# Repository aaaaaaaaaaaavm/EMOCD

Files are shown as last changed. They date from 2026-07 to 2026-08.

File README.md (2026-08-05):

# VOLLEY: an electromagnetic orbital CubeSat deployer

> **Numerical audit correction, 2026-08-03.** I corrected the winding-thickness quadrature
> and propagated the rated point to **11.03 N per kA/m, 16.388 m/s, 10.53 g, 20.99% net
> efficiency, and 65.552 N s per shot**. I also corrected A13's internal-momentum physics,
> replaced A6's fixed-shape covariance claim with a valid current-geometry slab bound,
> extended A12's stress plane, removed a 0.344 kg brake-fin double count, and corrected the
> fin thermal mass. Superseded values remain visible in their validation records and
> change log.

<p align="center">
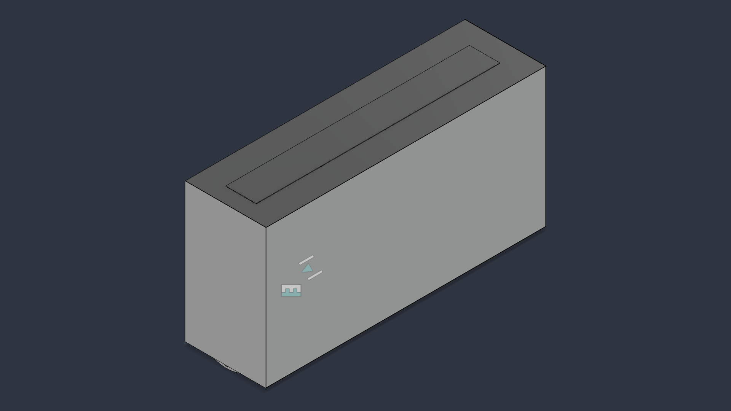
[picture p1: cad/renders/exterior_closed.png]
VOLLEY deployer, closed, mounted on its ESPA interface
  
</p>






A magazine-fed electromagnetic deployer that ejects unmodified CubeSats from a host
stage at programmable velocity, aimed at the unserved regime between spring deployers
(~2 m/s) and propulsive orbital transfer vehicles (hundreds of m/s).

**Status: design study, TRL 2-3.** Phase I CAD is complete across 9 Fusion 360 documents in three
generations, with Gen3 STEP exports committed. A provisional Gen4 open assembly exists in Fusion
but has no rated operating point or repository export yet ([status](docs/GEN4_STATUS.md)). **Nine of eleven planned validations
have run** — **two of them failed**, one found a published number 37 % high, and one returned
three rows that could not be evaluated at all. **Nothing has been built and nothing has been measured
at any scale.**
**Read `docs/PROVENANCE.md` before citing anything here.**

**[📄 One-page summary](SUMMARY.md)** · **[🧊 Frozen baseline](docs/BASELINE.md)** · **[Gen4 status](docs/GEN4_STATUS.md)** · **[🗺 Roadmap](docs/ROADMAP.md)** · **[⚠ Open problems](OPEN_PROBLEMS.md)** · **[✓ Validation](docs/VALIDATION_REPORT.md)** · **[🏗 Manufacturing](docs/MANUFACTURING.md)** · **[📐 ADRs](docs/adr/)** · **[📚 Literature](docs/LITERATURE.md)** · **[🎯 Research position](docs/RESEARCH_POSITION.md)** · **[⛔ Velocity ceiling](docs/VELOCITY_CEILING.md)** · **[☠ Kill criteria](docs/KILL_CRITERIA.md)** · **[🏁 Phase I closure](docs/PHASE_I_CLOSURE.md)** · **[📦 Payload classes](docs/PAYLOAD_CLASSES.md)** · **[📈 Market](docs/MARKET.md)**

<!-- PROGRAMME-HEADER-START -->
| Repository | Role | You are here |
|---|---|---|
| **[VOLLEY](https://github.com/aaaaaaaaaaaavm/VOLLEY)** | Flagship, authoritative engineering record, portfolio | |
| [VOLLEY-paper](https://github.com/aaaaaaaaaaaavm/VOLLEY-paper) | IEEE companion, manuscript and reproducibility package *(generated)* | |
| [VOLLEY-thesis](https://github.com/aaaaaaaaaaaavm/VOLLEY-thesis) | Thesis companion, university submission *(generated)* | |
| [VOLLEY-lab](https://github.com/aaaaaaaaaaaavm/VOLLEY-lab) | Phase II, research, redesign, deliberately unstable | |
<!-- PROGRAMME-HEADER-END -->

Four repositories, one programme, see **[`docs/PROGRAMME.md`](docs/PROGRAMME.md)**.

## The idea

CubeSats flown as rideshare secondaries inherit the primary customer's orbit. The
spring that ejects them adds 1-2 m/s, enough to drift clear, not enough to change an
orbit. A satellite with no propulsion of its own is stuck there for life.

VOLLEY replaces the spring with an ironless double-sided Halbach linear synchronous
motor driving a reusable magnetic sled along a 1.5 m track. Twelve 3U CubeSats feed
from two transverse cassettes and are fired one at a time. The satellite is never
modified, the magnets ride the sled, not the payload.

<table>
<tr>
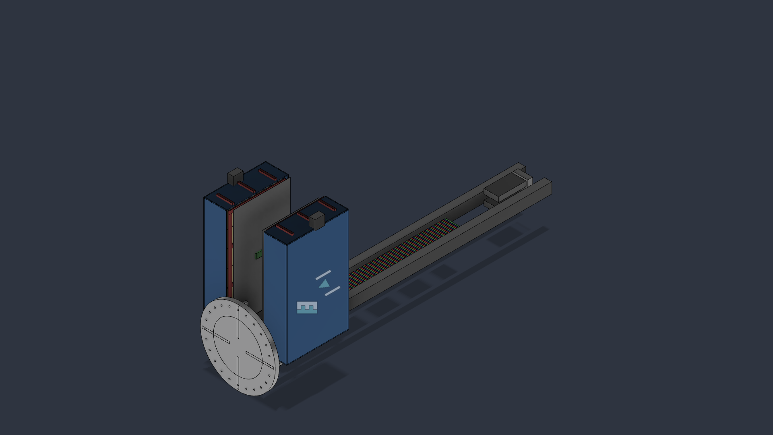
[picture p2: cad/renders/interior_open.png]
Interior, enclosure open
<td width="50%"><br><sub><b>Interior.</b> Track, stator belts, sled, and both cassettes with the enclosure open.</sub></td>
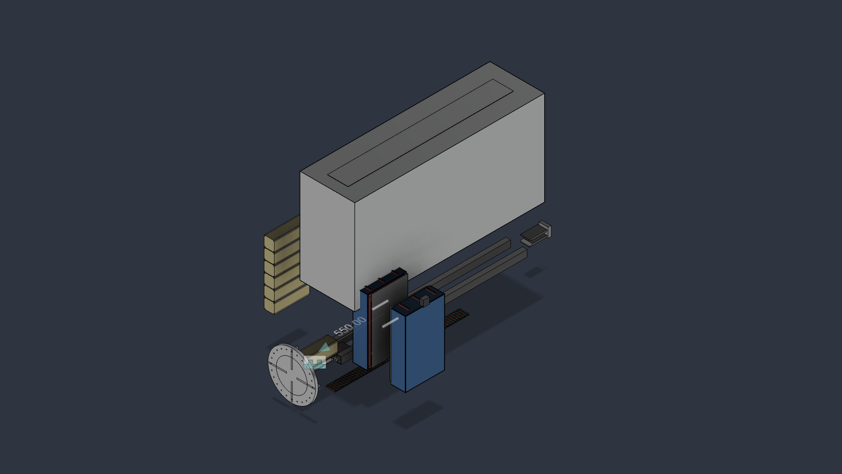
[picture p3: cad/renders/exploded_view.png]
Exploded view of the nine documents
<td width="50%"><br><sub><b>Exploded.</b> The nine documents: track, stator, sled, cassettes, brake, ESPA interface, enclosure, payload.</sub></td>
</tr>
<tr>
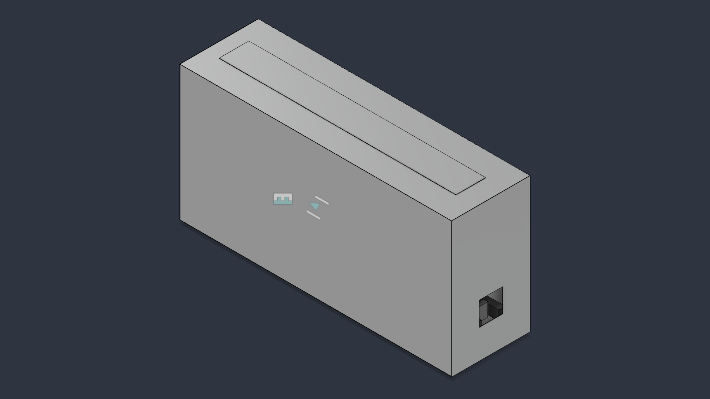
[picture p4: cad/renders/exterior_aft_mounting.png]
Aft ESPA mounting interface
<td width="50%"><br><sub><b>Aft mounting.</b> Ø460 mm ring flange, Ø400 mm bolt circle, 24 holes, four gussets.</sub></td>
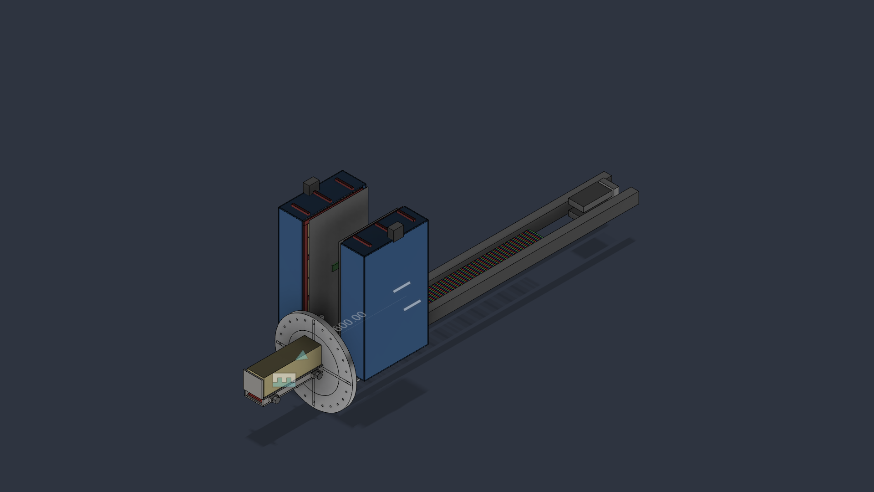
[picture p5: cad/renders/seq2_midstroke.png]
Sled at mid-stroke
<td width="50%"><br><sub><b>Mid-stroke.</b> Sled under thrust, payload still cradled, 158.6 ms from breech to release.</sub></td>
</tr>
</table>

**Spin it in the browser:** [`cad/stl/EMOCD_Assembly_Gen3.stl`](cad/stl/EMOCD_Assembly_Gen3.stl)
and [`cad/stl/EMOCD_Sled_Gen3.stl`](cad/stl/EMOCD_Sled_Gen3.stl), GitHub renders STL
natively, so click either and drag. They are derived meshes; `cad/step/gen3/` is the master
geometry ([why](cad/stl/README.md)).

## How a shot works

```mermaid
flowchart LR
    A["Cassette feed<br/>12 x 3U, two cassettes"] --> B["Retention gate<br/>preload into structure"]
    B --> C["Accelerate<br/>1.3 m, 10.5 g, 158.6 ms"]
    C --> D["Coast &amp; trim<br/>0.2 m"]
    D --> E["Release at 1500 mm<br/>16.39 m/s"]
    E --> F["Eddy brake<br/>1530-1740 mm"]
    F --> G["Sled recovered<br/>reusable, next shot"]
    E -.->|"payload departs"| H["Own orbit<br/>x1.62 lifetime"]
```

The satellite is never modified: the magnets ride the sled, not the payload. The sled leaves
release carrying 1268 J; 240 mm of stator past that point takes **291 J of it back into the
bank**, and the eddy brake absorbs the remaining 935 J. Efficiency is quoted
electrical-to-payload, net of that credit.

## Headline results (all model outputs, not measurements)

> ### The pulse-power chain does not close on purchasable cells
>
> **Found 2026-07-30, and stated here rather than left in the defect log.** The supercapacitor
> bank is modelled at 12 mÎ©. Commercial cells of this capacitance give **116 to 185 mÎ©**, and
> the shot stops completing above **65 mÎ©**: a source behind resistance R cannot deliver more
> than V²/4R, and this one is asked for 30 kW.
>
> **Exit velocity, stroke time and dispersion are unaffected** and the mechanical design is not
> implicated. What is affected is that the rated point assumes a bank nobody can buy. Fixing it
> is a sizing decision, costed at four parallel strings in `docs/PHASE_II.md` PII-7, and it is
> **not** silently applied here. See **P26**.

| Quantity | Value | Source |
|---|---|---|
| Thrust constant | 11.03 N per kA/m, ±0.99 % ripple, **independently computed by FEM to 0.03 %** | `analysis/motor_model.py`, A1 |
| Exit velocity, 3U | **16.39 m/s at 10.5 g** | `analysis/motor_model.py` |
| Electrical to payload efficiency | 21.0 % (2.56 kJ net of regeneration, 537 J delivered) | `analysis/motor_model.py` |
| Closed-loop dispersion | 0.027 m/s (3σ) at a 16.2 m/s setpoint to ±0.10 km apogee | `analysis/motor_model.py` |
| Orbital lifetime multiplier | x1.62 at mean activity, **not invariant, see P16** | `analysis/astro.py` |
| Constellation seeding | 30° in 1.4-6.9 days vs 25 days by differential drag | `analysis/astro.py` |
| Dry / loaded mass | 76.5 kg / 124.5 kg | `analysis/mass_properties.py` |
| Recoil per shot | 65.6 N·s | `analysis/astro.py` |
| Track first mode | 109 Hz fixed-fixed (target >70) | `analysis/sizing.py` |
| Energy closure | 100.0 % accounted | `analysis/sizing.py` |

> ### These numbers moved on 2026-07-29, downward
>
> The headline used to read **20.37 m/s at 16.3 g**, computed against a 4.86 kg parametric
> sled. Exact solid volumes from the Gen3 CAD give **9.445 kg**: the plates are drawn
> solid, with no pocketing (P15).
>
> That was not resolved by picking a number.
> [`validation/A4_sled_structural.md`](validation/A4_sled_structural.md) fixed the
> consequence of each outcome **before** the structural analysis ran:
>
> | Measured mass | Declared consequence |
> |---|---|
> | ≤ 5.35 kg | parametric model stands, 20.37 m/s holds |
> | 5.35-6.80 kg | neither estimate right |
> | **≥ 6.80 kg** | **the headline changes and the paper changes materially** |
>
> A4 has since run, the drawn plate passes all three structural bands, so nothing forces a
> lighter chassis, and the CAD result landed in the third branch. The scripts moved
> first, then the paper. Writing the rule down in advance is what made that a procedure
> rather than a preference.
>
> **What this costs and does not cost.** Exit velocity is down 19 % and efficiency from
> 32 % to 20 %, and to 19 % after the ESR correction of 2026-07-30 (P24); regeneration has
> then took it to 21.2 % (A11); the corrected quadrature now gives 21.0 %. The lifetime multiplier is down only 10 %, x1.80 to x1.62, because lifetime
> is a weak function of Î”v, the mission case survives better than the machine spec does.
> 9.445 kg is the **as-drawn, unpocketed** geometry, and A4 reports a 17x stress margin, so
> a rib-stiffened chassis would recover mass. Nobody has designed one
> ([`docs/ROADMAP.md`](docs/ROADMAP.md)).
>
> Ways to recover the velocity, pocketing, sheet current, stroke length, a two-layer
> stator, and a momentum-transfer release that buys it all back for 1.6 % of the shot
> energy, are costed in
> [`docs/DESIGN_OPTIONS_exit_velocity.md`](docs/DESIGN_OPTIONS_exit_velocity.md).

Three results have independent cross-checks: the Halbach field model (analytic vs
magpylib, agreeing to three digits, and again vs a meshed magnetostatic FEM, a PDE
solve rather than another superposition, agreeing on the corrected thrust constant to 0.03 %),
and orbital decay (orbit-averaged vs Cowell RK4, 99.4 %). Everything else is
single-sourced.

## Reproducing

```bash
pip install -r requirements.txt
cd analysis
python3 verify_field.py && python3 mass_properties.py && python3 motor_model.py && python3 sizing.py && python3 astro.py
```

Results land in `analysis/results/*.json`.

The analysis layer needs nothing but `requirements.txt`. The **validation** layer needs
external solvers, gmsh and scikit-fem for the magnetostatic FEM, GetDP, CalculiX,
ngspice, and a LaTeX install for the manuscript. `tools/env-setup.sh` installs all of
them on a Debian/Ubuntu machine and verifies each one before exiting.

<table>
<tr>
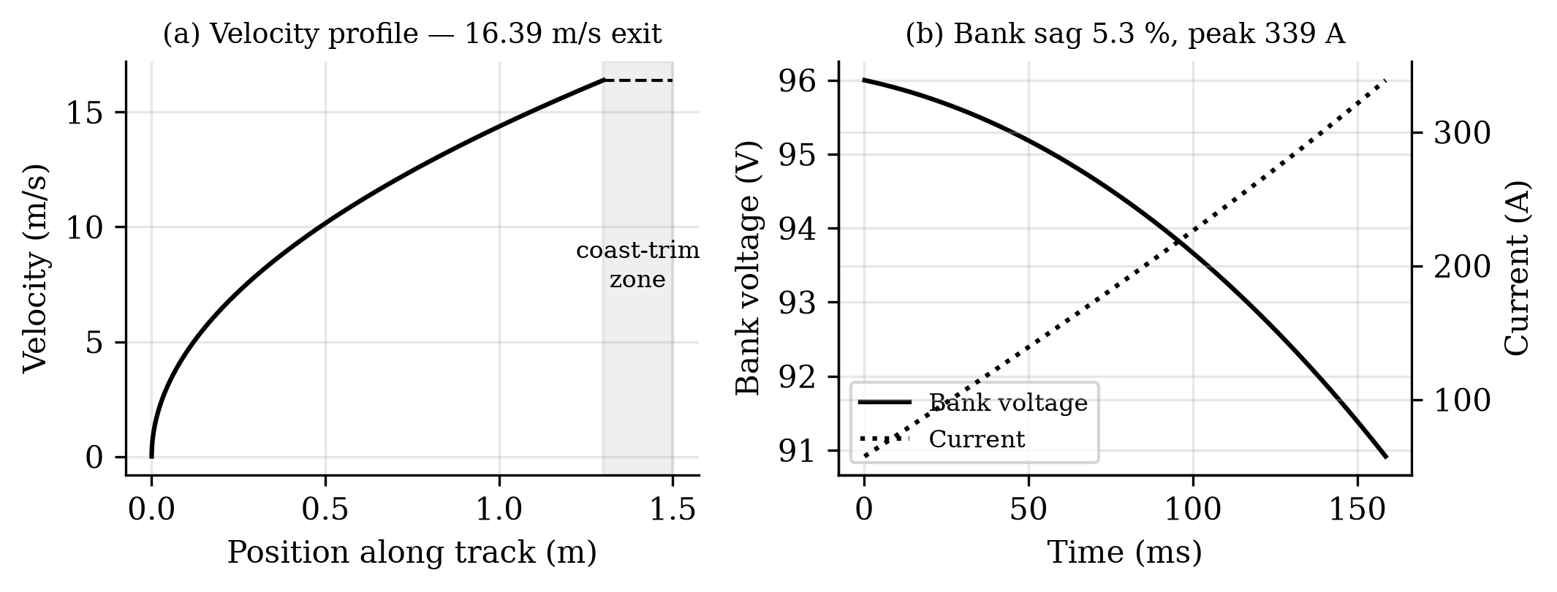
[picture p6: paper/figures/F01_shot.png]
Shot simulation: force, velocity, current
<td width="50%"><br><sub><b>The shot.</b> Force, velocity and current through the 158.6 ms stroke (<code>motor_model.py</code>).</sub></td>
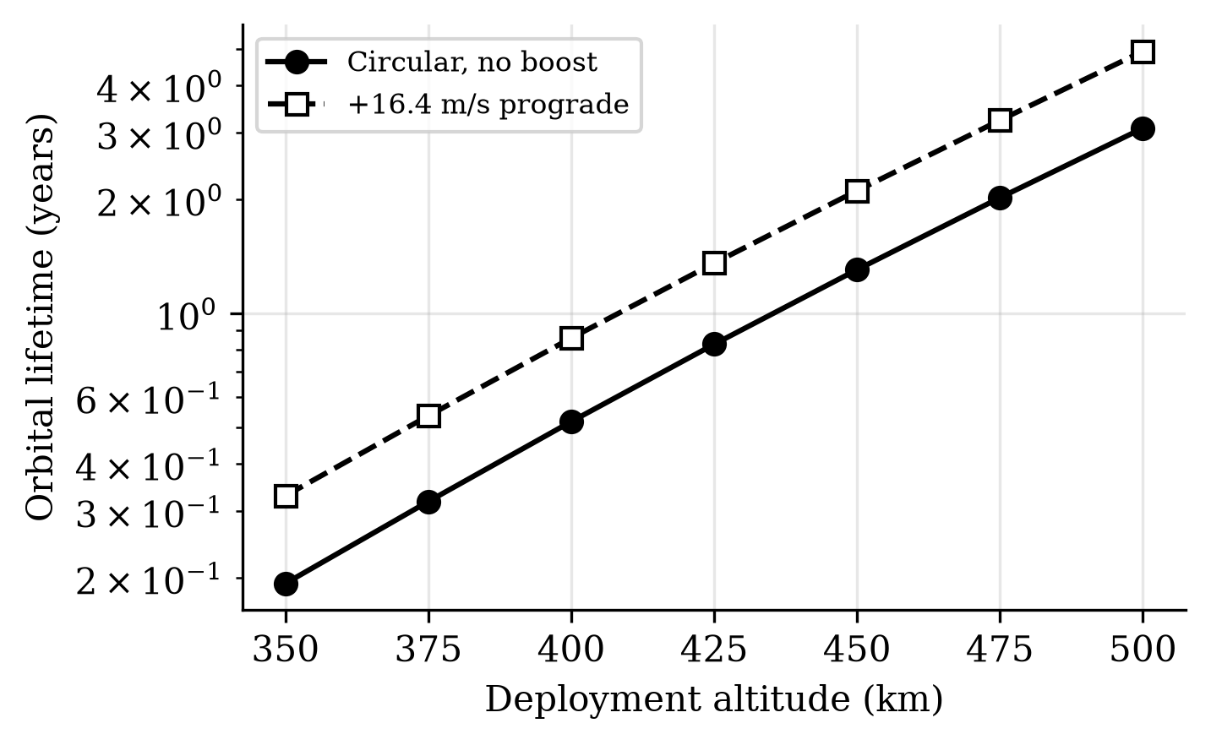
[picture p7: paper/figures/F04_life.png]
Orbital lifetime with and without the boost
<td width="50%"><br><sub><b>Lifetime.</b> Boosted vs unboosted decay, the x1.62 multiplier at mean activity is the current model result, not the absolute years (<code>astro.py</code>).</sub></td>
</tr>
</table>

## Validation

**[`docs/VALIDATION_REPORT.md`](docs/VALIDATION_REPORT.md)**: every claim, independently checked
where possible. Four analyses were actually run; three could not be.

- **Reproducibility holds exactly**: 173 values re-computed from clean, 173 identical.
- **GMAT falsified the invariance claim.** It reproduced the old x1.80 multiplier at mean
  and high solar activity but gave 2.074 at low, an 18.5 % spread against a ≤5 % band.
  `astro.py` varies solar activity by scaling density uniformly, and ballistic coefficient
  enters the same multiplicative slot, so *both* halves of that claim were tested by a sweep
  that could not have detected a problem (**P16**).
- **CalculiX** cleared the chassis on all three structural bands, which is what settled the
  sled mass at the CAD-derived **9.445 kg** and moved the headline to 16.54 m/s (**P15**), before the quadrature correction moved it to 16.39 m/s.
- **ngspice** reproduced the then-current shot model to 0.03 % and then, re-run at the then-current operating
  point, found a loss the analytic model had no term for at all: the bank's own series
  resistance, 86 J a shot (**P24**). Corrected, the two methods agree on peak current to
  0.01 %. It also found the quoted bank sag is state-of-charge, not the terminal voltage the
  drive sees.
- **A1 and A10--A13 have been propagated to the corrected point. A5 and the ngspice A8 run predate it** (**P19**) and needs
  re-running. A4 survives, its load being magnetostatic and velocity-independent.
- **A1 has run (2026-07-29).** A meshed 2-D magnetostatic FEM gives K<sub>t</sub> = 11.026 N
  per kA/m against the model's 11.03, **ratio 0.9997**, ripple 0.97 % against 0.99 %. The
  number every headline descends from is no longer checked only analytic-against-analytic.
  Two of seven bands missed, both with identified causes and neither a model error (P20, P21).
- **Not run:** A6, A7, A9.

## Charts

Full set in **[`docs/RESULTS.md`](docs/RESULTS.md)**: all drawn by GitHub from text, no image files.
Two that carry the argument:

```mermaid
pie showData
    title Energy per shot (J) - sizing.py energy_closure
    "Sled KE to the eddy brake" : 935
    "Payload KE, the useful output" : 537
    "Copper loss, shot + regen" : 850
    "Converter loss" : 111
    "Bank ESR loss" : 91
    "Auxiliary" : 35
```

537 J reaches the payload out of a **net 2560 J**: 2851 J leaves the bank and 291 J returns.
That is the 21.0 %. Efficiency fell with the heavier sled twice over, because more of the same
mechanical work goes into a mass that is then braked away and the longer 159 ms pulse accrues
more copper loss at unchanged current density. Regeneration is the first thing that has moved
it the other way.

**This page said "no regeneration credit" until 2026-07-31**, on the strength of a 2025
decision that argued the motor cannot *arrest* the sled. It cannot, and the brake stays. It was
never shown that no energy could be recovered, and
[`validation/A11_regen_braking.md`](validation/A11_regen_braking.md) found 23.0 % of the sled's
energy available inside the existing envelope at the existing current rating.

The 86 J ESR slice was not here until 2026-07-30. No script modelled the bank's series
resistance, so the loss existed in the hardware and nowhere in the accounting. A circuit
simulation found it (P24).

```mermaid
xychart-beta
    title "Minimum approach vs ejection velocity - not a robust quantity"
    x-axis "Ejection velocity (m/s)" [20.00, 20.37, 20.50, 20.65, 21.00]
    y-axis "Minimum approach (km)" 0 --> 70
    line [37.5, 4.6, 56.1, 45.3, 63.4]
```

A ±2.5 % velocity change moves the conjunction minimum from 4.6 km to 63.4 km. That is why
the paper's safety claim rests on the realignment period, now 9.9 days at the current
operating point, instead of a single distance (P1). The sweep above was computed at the
superseded 20.37 m/s point and is kept as the evidence for P1; the fragility it demonstrates
is a property of the beat geometry, not of any one velocity.

## Validation status

Each analysis has its acceptance band declared **before** the run, in
[`validation/`](validation/). A5 has now been run under GMAT; the rest have not, a cross-check whose target is chosen after seeing the
answer proves nothing.

| Analysis | Tool | Closes | Status |
|---|---|---|---|
| A1 airgap field | FEMM | E1 (2-D half), E2 | specified |
| **A4 sled chassis** | CalculiX ccx 2.21 | **P5, P8** | **run**: as-drawn plate passes; mass unchanged |
| A5 lifetime & seeding | GMAT R2022a | E6 | **run**: see [`docs/RESULTS.md`](docs/RESULTS.md) |
| A6 conjunction Pc | NASA CARA | P1 | specified |
| A7 separation & tip-off | Project Chrono | E7 | specified |
| A8 pulse-power chain | ngspice 42 | E17 | **run**: bands met, 2 findings |

## Host integration, worked against real vehicles

The interface asks four things of any host: mass and control authority, a 150-300 W recharge
feed, a serial command link, and an authorized firing window. Two Indian candidates are
worked as examples in the paper because both exist today.

**ISRO's POEM** is the flown precedent, a spent PS4 stage operated as a three-axis-stabilized
hosted platform with solar power, NavIC navigation and helium attitude thrusters, retired by
controlled reentry. It supplies everything the attached variant borrows, and its zero-debris
closeout is the regulatory template.

**Skyroot Aerospace's Vikram-1** carries a restartable liquid Orbit Adjustment Module, one
Raman-2 engine, four Raman Mini thrusters, eight cold-gas thrusters, stage-tested through more
than a thousand pulses, whose stated multi-orbit deployment role is functionally the PS4's.
Against the vehicle's published 350 kg LEO capacity, a loaded VOLLEY is **34 %**, falling to
**22 %** and **13 %** on the announced 550 kg and 900 kg family members. Early flights are
therefore dedicated demonstrations and later ones ordinary manifest items.

One integration quantity cannot be closed from public data: the OAM's mass and control
authority are undisclosed, which is why the recoil budget is parametric. Obtaining stage mass,
thruster impulse budget and coast duration is the single data exchange that converts this
analysis from parametric to specific, for any candidate vehicle, Indian or otherwise.

Recoil is the satellite's momentum only, **65.6 N·s** per shot, nulled by a few grams of cold
gas. Comparison against fielded deployers and transfer vehicles, including Dhruva Space's
flown DSOD, is in [`docs/LANDSCAPE.md`](docs/LANDSCAPE.md).

## Repository layout

- `analysis/`, current scripts; these reproduce the numbers above
- `analysis/femm/`, FEMM magnetostatics package: `emocd_cross_section.dxf` + `FEMM_RUN_SHEET.md` (analysis A1, not yet run)
- `cad/`, Fusion 360 CAD: `parameters.json` (geometry source of truth, 9 documents),
  `step/gen1|gen2|gen3/` exports (**Gen3 current**), `stl/` (browser-viewable meshes),
  `renders/`, `CHANGELOG_CAD.md` (generation history and per-file defect list)
- `legacy/`, superseded scripts, kept for history, **do not cite**
- `paper/`, IEEE conference paper (LaTeX source, figures, PDF)
- `validation/`, independent cross-check plan (FEMM, CalculiX, Orekit, CARA, Chrono),
  each with an acceptance band declared before the run; nothing run yet
- `docs/`, computation notes, FEMM run sheet, related work and comparator sources
- `docs/PROJECT_NOTES.md`, working context: ground rules, layout, locked decisions
- `docs/LANDSCAPE.md`, how this compares with deployers that actually fly
- `docs/DESIGN_OPTIONS_exit_velocity.md`, options for the P15 velocity shortfall, costed
- `docs/INVENTORY.md`, complete indexed catalogue of every calculation, decision and artifact
- `docs/DECISION_LOG.md`, why each design change happened, including two self-corrections
- `docs/PROVENANCE.md`, what came from where, and what was never verified
- `OPEN_PROBLEMS.md`, known errors in the paper, and unsolved engineering
- `docs/PROGRAMME.md`, the four repositories and how they relate
- `docs/BASELINE.md`, the frozen Phase I baseline (generated) and its change-control rule
- `docs/GEN4_STATUS.md`, provisional open-assembly geometry and the export/performance gate
- `docs/HISTORY.md`, project timeline since 2021, and how the git history was reconstructed
- `docs/programme/`, the governing dossier, adopted verbatim, plus its amendment record
- `docs/adr/`, nineteen architecture decision records
- `docs/PHASE_II.md`, deferred work and the gate it must clear to return
- `docs/MANUFACTURING.md`, tolerance stack, assembly hazard, make-vs-buy
- `docs/CROSS_INDUSTRY.md`, which open items are actually solved elsewhere
- `docs/QUALIFICATION_PLAN.md`, environmental and qualification campaign, specified not run
- `docs/BENCHTOP_TESTS.md`, four cheap sub-scale experiments, bands declared in advance
- `analysis/cost.py`, parametric BOM; every price assumed, structure is the deliverable

## Known issues

The published paper previously contained four numbers its own scripts did not reproduce
(conjunction minimum, peak current, far-field stray values, brake fin temperature rise),
all found by reconstructing the analysis from scratch. **All four were corrected in
`paper/paper.tex` on 2026-07-23 to match the scripts**, and the conjunction claim was
additionally reframed because that minimum is not a robust quantity. Note that
`paper/archive/EMOCD_submission_uncorrected.pdf` still carries the uncorrected values,
whether that build is the one that was submitted is open (`OPEN_PROBLEMS.md` P11). Full record with
cause, before/after, and references is in `CHANGELOG.md`; the original defects remain
documented in `OPEN_PROBLEMS.md` P1, P4 for the audit trail.

**Two issues are live rather than historical, and both sit in the paper:**

- **P16, the invariance claim in the abstract is falsified.** GMAT reproduces the x1.80
  lifetime multiplier at mean and high solar activity but gives x2.074 at low, an 18.5 %
  spread against a ≤5 % band. The reason is that `astro.py` varies solar activity by scaling
  density uniformly, which preserves a ratio *by construction*, and the ballistic-coefficient
  half of the same sentence is the identical construction, since `scale` and `1/BC` occupy the
  same slot in the drag term. Neither half of that claim was ever tested by a method capable
  of falsifying it. **`paper/paper.tex` still asserts it in five places, including the
  abstract**, because there is no TeX engine here and editing the source without rebuilding
  the PDF would split the two.
- **P11, which build was actually submitted is unresolved.** Until that is answered, it is
  not known whether the version of record carries P1, P4 *and* the falsified abstract claim.

Newest entries: **P26** (the supercapacitor bank cannot source the shot on purchasable
cells), **P28** (the regeneration stator and the eddy fin do not both fit the arrest section)
and **P29** (the paper says the winding is segmented; the model charges copper for all
1.3 m). Most recently closed: **P17**, the inter-array attraction feeding the A4 FEA, 37 %
high — resolved by A12, which also found that P17's *explanation* of its own finding was
backwards.

## Author

**Adityavardhan Mishra**: Department of Mechanical Engineering, Symbiosis Institute of
Technology, Symbiosis International (Deemed University), Pune. Project begun April 2021.

📧 [adityavardhanmishr@gmail.com](mailto:adityavardhanmishr@gmail.com)

Questions, corrections and reproduction attempts are all welcome, particularly reproduction
attempts. If a number in this repository does not reproduce for you, that is a defect and I
want to know. See [`docs/CONTRIBUTING.md`](docs/CONTRIBUTING.md).

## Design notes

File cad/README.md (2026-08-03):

# CAD

Fusion 360 CAD for VOLLEY, across nine documents (Track, Stator, Sled, Payload_3U,
Magazine_Cassette, Brake, Interface_ESPA, Enclosure, Assembly), in **three generations**.

Full generation history, per-file body counts, and the defect list are in
[`CHANGELOG_CAD.md`](CHANGELOG_CAD.md).

## Generations

| Folder | What it is | Status |
|---|---|---|
| `step/gen3/` | Parameter-reconciled revision, plus `EMOCD_Gen3.step`, a monolithic single-file model (395 solids) holding all nine sub-systems. The renders in `renders/` came from it | **CURRENT.** Open problems P5, P12 are indexed against it |
| `step/gen2/` | First structured revision. Mechanism-level detail arrives: single-layer stator, sled Halbach arrays and rollers, magazine escapement and D6 pins, brake ring spring | SUPERSEDED, carries a 360 mm sled chassis where the spec says 488 mm |
| `step/gen1/` | The original CAD, 2021-2025. Structural envelope rather than mechanism model; the geometry `parameters.json` was reverse-engineered from. Includes the pre-split single-file `EMOCD_Deployer_Assembly_Gen1.step` and a second sled revision, `Sled_Gen1b` | SUPERSEDED, heritage only |

Use Gen3 unless you specifically need a heritage comparison.

## What is authoritative here

- **`parameters.json` is the geometry source of truth.** Every dimension lives here, not
  in Fusion (Fusion user parameters are document-scoped and drift silently across the nine
  documents). Change a value here, then regenerate the affected document from script. If
  the CAD and `parameters.json` disagree, `parameters.json` wins and the CAD is wrong.
- CAD is authoritative for **geometry, fit, and interference only.**
- `analysis/*.py` remains authoritative for **mass and performance.** Fusion-computed
  masses are proxies (solid-copper stator, solid-aluminium CubeSats, steel standing in for
  NdFeB) and are deliberately excluded from `parameters.json`. **Never quote a
  Fusion-computed mass.**

## Status (2026-07-28)

First-pass CAD, **no structural or magnetic FEA behind any of it.** Several values are
flagged `PROVISIONAL_PENDING_FEA` in `parameters.json`. Open: the sled chassis mass (P5),
the resulting exit velocity (P8), the ESPA envelope overrun (P9), the incomplete mass
rollup (P10), and the CAD-side geometry defects P14, see `../OPEN_PROBLEMS.md`.

**What changed on 2026-07-28.** The previously committed `step/*.step` set was a
mixed-generation snapshot matching no single generation, and two of its files were stubs:
the stator export contained **one solid** rather than 162 conductors, and the ESPA
interface contained **one solid** rather than a flange ring, hub plate, and four gussets.
It was replaced wholesale by the three audited generations. See `CHANGELOG.md` (CAD2 block)
and `OPEN_PROBLEMS.md` P13.

## Before using any file

1. **Gen3 unless you need heritage.** Gen1 and Gen2 carry known dimensional and mechanism
   defects, listed per file in `CHANGELOG_CAD.md`.
2. **Cross-check every dimension against `parameters.json`** before quoting it.
3. **No Fusion masses.** Mass authority is `analysis/mass_properties.py`, and even that is
   incomplete (P10).
4. **The sled mass conflict is resolved (2026-07-29).** The scripts now carry the CAD-derived 9.445 kg and the headline is 16.39 m/s. Historical note follows: 20.37 m/s assumed a 4.86 kg sled; the Gen3
   geometry implies ~7.50 kg and a provisional 17.88 m/s. Quote neither without the
   conflict (P5, P8). `validation/A4_sled_structural.md` is the analysis that settles it.
5. **The ESPA envelope claim is not supported.** 1839 mm installed against a ~1270 mm class
   limit, ~44 % over (P9), and the paper still asserts compatibility (P12).
6. **The stator layer count is an open design decision.** Gen1 built two layers, Gen2 and
   Gen3 one, and `parameters.json` flags it open. The electromagnetic consequence, roughly
   x2 force for the same current against x2 copper mass and winding complexity, has never
   been computed (P14).

## Contents

- `parameters.json`, the 9-group geometry parameter set, source of truth
- `CHANGELOG_CAD.md`, generation history, per-file inventories, defect IDs (G1-D*, G2-D*,
  G3-D*), and the cross-generation comparison
- `step/gen1/`, `step/gen2/`, `step/gen3/`, STEP exports (`.f3d` is not diffable, so STEP
  is what gets committed)
- `renders/`, exterior, interior, exploded, and firing-sequence PNGs, from the Gen3
  monolithic model

The 2-D magnetic cross-section and its FEMM run sheet live in `../analysis/femm/`.

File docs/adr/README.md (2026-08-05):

# Architecture Decision Records

Required by the Engineering Programme Dossier and the TRB prompt. One file per decision, in a
fixed shape, so a decision can be audited without reading a narrative.

**[`../DECISION_LOG.md`](../DECISION_LOG.md) is not superseded.** It is the readable history
and remains the better document for understanding *how the project got here*. These records are
the structured view: what was decided, what else was considered, what it costs, and how it gets
validated. Where an ADR has a Context section, that prose usually came from the decision log.

## Template

```
# ADR-NNN, title

Status · Date · Phase
## Context, the forces at play, including what was not known
## Decision, what was decided, stated flatly
## Alternatives, what else was considered, and why it lost
## Consequences, what this costs, including the bad parts
## Validation, how we would find out this was wrong
```

**The Consequences and Validation sections are the ones that matter.** A record listing only
benefits is advocacy, not a decision record, and one with no validation path violates dossier
§7, every feature needs a path toward validation.

## Index

| ADR | Decision | Status | Phase |
|---|---|---|---|
| [001](001-electromagnetic-deployment.md) | Electromagnetic deployment instead of a spring | Accepted | Concept |
| [002](002-host-is-a-spent-upper-stage.md) | Host is a spent upper stage, not a free-flyer | Accepted | Concept |
| [003](003-linear-synchronous-motor.md) | Linear synchronous motor, not a coilgun | Accepted | **Load-bearing** |
| [004](004-ironless-stator.md) | Ironless stator | Accepted | I |
| [005](005-eddy-brake-not-regeneration.md) | Eddy-current brake; sled energy is dissipated | Accepted | I |
| [006](006-magnets-ride-the-sled.md) | Magnets ride the sled; the CubeSat is unmodified | Accepted | **Load-bearing** |
| [007](007-dual-transverse-cassettes.md) | Dual transverse cassettes | Accepted | I |
| [008](008-retention-gate.md) | Retention gate separates preload from release | Accepted | I |
| [009](009-coast-and-trim.md) | Coast-and-trim release zone | Accepted | I |
| [010](010-host-agnostic-interface.md) | Host-agnostic four-item interface | Accepted | I |
| [011](011-publish-publicly.md) | Publish publicly, defects included | Accepted | I |
| [012](012-adopt-measured-sled-mass.md) | Adopt the measured 9.445 kg sled | Accepted | I |
| [013](013-drop-invariance-claim.md) | Drop the lifetime-ratio invariance claim | Accepted | I |
| [014](014-fleet-setpoint-below-ceiling.md) | Fleet setpoint at 98.2 % of the open-loop ceiling | Accepted | I |
| [015](015-derive-not-paste.md) | Derive coupled values; never paste them | Accepted | I |
| [016](016-reconstructed-history.md) | Reconstruct git history with labelled dates | Accepted | I |
| [017](017-four-repositories.md) | Four repositories, two of them generated | Accepted | I |
| [018](018-programme-name.md) | VOLLEY is the programme name; EMOCD_ remains the part prefix | Accepted | Programme |
| [019](019-gen4-open-assembly-before-export.md) | Keep Gen4 open assembly separate from the Phase I baseline | Accepted | Gen4 transition |
| [020](020-inter-shot-cadence.md) | The inter-shot cadence is 1200 s, closing P31 | Accepted | Load-bearing |

Every decision in `DECISION_LOG.md` appears above. ADRs 012-018 record decisions that were
never written down anywhere before.

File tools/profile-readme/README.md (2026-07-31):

## Adityavardhan Mishra

**Mechanical engineer. Powertrain, ECUs, CubeSat deployment. Asking spacecraft inconvenient questions.**

BTech Mechanical Engineering, Symbiosis Institute of Technology, Pune · 2023-2027

In 2021 I got stuck on a dumb question: why do we still deploy CubeSats with springs. I never
really got unstuck. That question is now **VOLLEY**: an electromagnetic deployer that ejects
unmodified 3U CubeSats at a programmable velocity, around seven times what a spring gives you, from a
spent rideshare upper stage. I've presented it at DRDO ARDE and the India Science Festival.

Before that there was rocketry, where our payload took **2nd globally** at the SDL Payload
Challenge, IREC 2025 in Texas. Alongside it there are engines, I run Poona Motor Club, tune Royal
Enfield, KTM and Honda platforms, and when Powertronic's map files turned out to be an obfuscated
binary I reverse-engineered the format and built a dual-map editor so I could stop guessing. This
year I'm on powertrain for our Formula Student team.

Aerospace, telecom software, engines. I have a hunch they all come from the same place. Haven't
proven it yet.

---

### The thing I'd actually like you to look at

**[VOLLEY](https://github.com/aaaaaaaaaaaavm/VOLLEY)**, a magazine-fed ironless double-sided
Halbach linear synchronous motor that ejects unmodified CubeSats at 16.5 m/s, 10.7 g, on a net
2.58 kJ a shot. TRL 2-3, nothing built, nothing measured.

**Open it for the defect record, not the numbers.** Thirty-one numbered defects, published as I
find them, including the ones that damage the claims. An independent propagator falsified a claim
in my paper's own abstract; that's P16, logged rather than quietly dropped. The supercapacitor bank
turns out not to be buyable at the resistance the design assumes, which is P26 and is on the front
page. A force I'd been feeding into my own structural FEA was 37 % too high, and when I chased it
down, the *explanation* I'd written for it was backwards too.

**Acceptance bands go in the repository before each analysis runs**, so a miss can't be
rationalised afterwards. Three rows of one analysis came back not-pass and not-fail but **void** —
the quantity they tested didn't exist — and they're recorded that way, because a band you can
reinterpret isn't a band.

That habit is the actual portfolio: **[skills, with the file that proves each one](https://github.com/aaaaaaaaaaaavm/VOLLEY/blob/main/docs/SKILLS.md)**

| | |
|---|---|
| 🛰 **[VOLLEY](https://github.com/aaaaaaaaaaaavm/VOLLEY)** | The engineering record. Start at `SUMMARY.md` |
| 📄 **[VOLLEY-paper](https://github.com/aaaaaaaaaaaavm/VOLLEY-paper)** | IEEE manuscript + reproducibility package. Reproduces from a clean clone |
| 🎓 **[VOLLEY-thesis](https://github.com/aaaaaaaaaaaavm/VOLLEY-thesis)** | Final-year submission |
| 🧪 **[VOLLEY-lab](https://github.com/aaaaaaaaaaaavm/VOLLEY-lab)** | Where I'm allowed to break things. Nothing here is citable |

---

### What I actually do

**Simulation**: scikit-fem, gmsh, GetDP, CalculiX, ngspice, GMAT, magpylib. I wrote a 2-D
magnetostatic FEM from the weak form to check my own thrust constant; it agreed to 0.07 %, which
was the first time that number rested on a PDE solve instead of superposition.

**CAD/CAE**: Fusion 360, SolidWorks, AutoCAD, ANSYS. Three CAD generations of the deployer, all
in the repo as STEP.

**Engines**: combustion airflow, head porting, camshaft profiling, ECU calibration. 46 to ~60 bhp
on an RE Super Meteor 650, dyno-validated across the band.

**Code**: Python for the numerics, MATLAB, C. Applied AI at work: I own AI systems architecture
and product design for a telecom CRM platform, which is not what I was hired to do.

<sub>Hindi and English native · Marathi, Maithili · Russian, French elementary. Friends call me AVM,
pronounced how it's spelled, *Aevium*. Recognised by the ISRO Chairman for aerospace STEM
outreach; member, Space Generation Advisory Council.</sub>

📫 [adityavardhanmishr@gmail.com](mailto:adityavardhanmishr@gmail.com) ·
[LinkedIn](https://www.linkedin.com/in/adityavardhanmishra/) · Pune, India

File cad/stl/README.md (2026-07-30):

# STL meshes: derived, not authoritative

GitHub renders `.stl` in an interactive viewer and does **not** render STEP, so these two
meshes exist purely so the geometry can be spun in a browser. Click either file above.

**These are derived artifacts.** `../step/gen3/*.step` is the master geometry and
`../parameters.json` is the source of truth for every dimension. A mesh is a faceted
approximation, never measure anything off it.

| File | Source | Mesh size | Triangles | Bounding box |
|---|---|---|---|---|
| `EMOCD_Assembly_Gen3.stl` | `../step/gen3/EMOCD_Assembly_Gen3.step` | 40 mm max | 50,692 | 1995x 530x 940 mm |
| `EMOCD_Sled_Gen3.stl` | `../step/gen3/EMOCD_Sled_Gen3.step` | 8 mm max | 23,332 | 616x 172x 140 mm |

Regenerate with:

```python
import gmsh
gmsh.initialize()
gmsh.option.setNumber('Mesh.CharacteristicLengthMax', 40)   # 8 for the sled
gmsh.option.setNumber('Mesh.CharacteristicLengthMin', 10)   # 2 for the sled
gmsh.option.setNumber('Mesh.Binary', 1)
gmsh.merge('../step/gen3/EMOCD_Assembly_Gen3.step')
gmsh.model.mesh.generate(2)
gmsh.write('EMOCD_Assembly_Gen3.stl')
gmsh.finalize()
```

`pip install gmsh` (its OCC reader handles STEP). On a headless Linux box it also needs
`libglu1-mesa libxft2 libxinerama1 libxcursor1 libfontconfig1`.

Each mesh was checked against its STEP source by bounding box on generation. The sled
matches exactly at 616x 172x 140 mm. The assembly measures 1995 mm in X against a
point-cloud bound of 1998 mm on the STEP, the 3 mm is spline control points lying outside
the surface they define, which is expected and harmless.

**One thing the assembly mesh exposes:** its X range is −188 to 1810 mm, where
`parameters.json` records the installed envelope as −32 to 1807 mm. Something sits 156 mm
further aft than the recorded envelope. See `../../OPEN_PROBLEMS.md` P14.

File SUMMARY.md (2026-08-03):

# VOLLEY: one page

**Adityavardhan Mishra** · Dept. of Mechanical Engineering, Symbiosis Institute of
Technology, Symbiosis International (Deemed University), Pune
· [adityavardhanmishr@gmail.com](mailto:adityavardhanmishr@gmail.com)
· [full repository](https://github.com/aaaaaaaaaaaavm/VOLLEY)

---

## The idea

Rideshare CubeSats inherit the orbit of whoever paid for the launch. Spring deployers release
them at **1-2 m/s**, which is far too little to change that orbit; orbital transfer vehicles
can change it, but they cost hundreds of m/s of propulsion and a spacecraft to carry it.
Between those sits an unserved regime.

**VOLLEY is a magazine-fed linear synchronous motor** that mounts on a rideshare upper stage
and ejects **unmodified** 3U CubeSats, no armature, no plating, no electrical interface on
the customer satellite, at a **velocity programmable per satellite**. Twelve satellites feed
from two transverse cassettes onto a reusable permanent-magnet sled running a 1.5 m ironless
double-sided Halbach track, arrested by a contactless eddy brake and powered from a
supercapacitor bank.

One shot buys a propulsion-less satellite **1.62x its orbital lifetime**, or seeds 30° of
constellation phase spacing in **1.4-6.9 days** against roughly 25 for differential drag.

## The numbers, with their caveats attached

| | | |
|---|---|---|
| Exit velocity, 3U | **16.4 m/s at 10.5 g** | **6.6x the fastest published spring** (NRCSD-E specifies 0.5-2.5 m/s; the widely quoted "8x" is against 2 m/s and is the softer comparison). The ceiling is the payload's g-limit, not the machine: 25.3 m/s at the 25 g cap, see [`VELOCITY_CEILING.md`](docs/VELOCITY_CEILING.md). From a sled mass computed from CAD solid volumes (9.445 kg), not estimated, the earlier 4.86 kg parametric estimate gave 20.4 m/s |
| Velocity dispersion | **0.027 m/s (3σ)** | Closed-loop, at a 16.2 m/s setpoint. Rests on *assumed* sensor noise (E7), the differentiator, and the least validated part |
| Thrust constant | **11.03 N per kA/m** | Winding-resolved, and **independently computed by a meshed magnetostatic FEM to 0.03 %**, a PDE solve, not another superposition |
| Energy per shot | **2.85 kJ gross, 2.56 kJ net**, 21.0 % electrical-to-payload | Under one watt-hour. 291 J of the sled's 1268 J comes back through 240 mm of regen stator ([A11](validation/A11_regen_braking.md), adopted 2026-07-31); the brake still takes 935 J |
| System mass | **76.5 kg dry**, 124.5 kg loaded | **6.38 kg of deployer per 3U satellite**, the same class as canisterized dispensers at ~2 kg/U |
| Recurring hardware | ~₹1.35 M per unit, ₹112 k per satellite | **Every price assumed, no quotations.** Useful part: avionics + energy storage are ~42 % of cost and the magnet set only ~5 %, which holds even at 2x price errors |
| Envelope | 1839 mm closed | **Exceeds the ESPA-Grande class by ~44 %.** Open packaging problem (P9) |

> **Open as of 2026-07-30:** the supercapacitor bank is modelled at an ESR no commercial cell
> of that capacitance achieves, and the shot does not close at a realistic value (**P26**). The
> velocity and dispersion figures are unaffected, the bank sizing is. Not quietly re-sized.

**Maturity: TRL 2-3. Nothing has been built, fired, or measured.** **Nine of eleven** specified
validations have been run, each against an acceptance band declared *before* the run — and the
results are mixed on purpose:

| | |
|---|---|
| **A5 FAILED** | an independent propagator falsified an invariance claim that was in the paper's own abstract (P16) |
| **A12** | found the inter-array force feeding the structural FEA **37 % high** — and that the explanation first written for it was backwards |
| **A6** | returned three rows **void**: the quantity they tested does not exist at these separations |
| **A13 FAILED / corrected** | transient return rate still misses rows 3 and 4, but the ideal residual rate is zero; the former 18.1 s cadence floor is superseded, while attitude restoration and structural settling remain open (E25) |
| A1, A4, A10, A11, A12 | passed, partially or fully, with every miss logged; the ngspice A8 run now predates the corrected operating point |

**A7 (tip-off) and A9 (decay against flown CubeSats) are outstanding.** A9 is the only analysis
anywhere in this project that compares the model against something that actually happened, and
it is blocked by network policy rather than by difficulty.

## Where it sits against what flies

| | Î”v | Programmable | Satellite mods | Status |
|---|---|---|---|---|
| Spring deployers, P-POD, ISIPOD, **Dhruva DSOD** | 1-2 m/s | no | none | flown, thousands deployed |
| **VOLLEY** | 16.4 m/s | **yes** | **none** | design study |
| Transfer vehicles, ION, Vigoride | 100s m/s | yes | mounting | flown, commercial |

Dhruva Space's DSOD is the closest comparator and it already flies, space-qualified on
PSLV-C53 and C55, non-pyrotechnic release, and instrumented to *measure* ejection velocity on
orbit. What it cannot do is exceed 2 m/s or vary velocity per satellite. That gap is the
entire argument for this machine, and it is narrower than "electromagnetic beats springs".

## Host integration, worked against real vehicles

The interface asks four things of any host: mass and control authority, a 150-300 W recharge
feed, a serial command link, and an authorized firing window.

- **ISRO's POEM** is the flown precedent, a spent PS4 operated as a three-axis-stabilized
  hosted platform, retired by controlled reentry. Its zero-debris closeout is the regulatory
  template.
- **Skyroot's Vikram-1** carries a restartable Orbit Adjustment Module stage-tested through
  more than a thousand pulses. A loaded VOLLEY is **34 %** of the published 350 kg LEO
  capacity, falling to **22 %** and **13 %** on the announced 550 kg and 900 kg variants, so
  early flights are dedicated demonstrations and later ones ordinary manifest items.

Recoil is the satellite's momentum only, **65.6 N·s** per shot, nulled by a few grams of cold
gas.

## What makes this repository worth opening

Every defect found in this work is published, numbered, and tracked, including the ones that
damage its own claims. Acceptance bands are declared in writing **before** each analysis runs,
so a failure cannot be rationalised afterwards. Four errors were found in the paper by
rebuilding its analysis from scratch. An independent propagator (GMAT) then **falsified a
claim in the paper's own abstract**, and that is recorded as P16 rather than quietly dropped.
The scripts are authoritative over the paper, never the reverse.

**[`docs/PROGRAMME.md`](docs/PROGRAMME.md)**: the four repositories of this programme
**[`docs/BASELINE.md`](docs/BASELINE.md)**: what is frozen, and what may move it
**[`docs/GEN4_STATUS.md`](docs/GEN4_STATUS.md)**: what exists in the provisional open assembly, and what is not yet calculated
**[`docs/ROADMAP.md`](docs/ROADMAP.md)**: what happens next, and when
**[`docs/HISTORY.md`](docs/HISTORY.md)**: the project since 2021, and how this git history was built
**[`docs/QUALIFICATION_PLAN.md`](docs/QUALIFICATION_PLAN.md)**: the test campaign, specified
**[`OPEN_PROBLEMS.md`](OPEN_PROBLEMS.md)**: every known defect
**[`docs/VALIDATION_REPORT.md`](docs/VALIDATION_REPORT.md)**: every claim, independently checked where possible
**[`docs/PROVENANCE.md`](docs/PROVENANCE.md)**: read this before citing anything

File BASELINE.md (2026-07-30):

# Phase I frozen baseline

> **Generated by `tools/make_baseline.py` from `analysis/results/*.json`. Do not hand-edit.**
> Every value below is read from the scripts at generation time, so this file cannot silently
> disagree with them. Regenerate after any authorised baseline change.
>
> Flagship commit at generation: `1d01ba7` · Phase **I** · governed by
> [`docs/programme/ENGINEERING_PROGRAMME.md`](docs/programme/ENGINEERING_PROGRAMME.md)

This is the engineering baseline the Phase I deliverables (portfolio, IEEE paper, thesis)
are developed against. Dossier §2 requires it to be stable. The change-control rule below is
what makes "stable" mean something.

**These are model outputs.** Nothing here has been measured. See
[`PROVENANCE.md`](PROVENANCE.md) before citing any of it.

## The baseline

| Quantity | Value | Source field |
|---|---|---|
| Thrust constant | **11.22 N per kA/m, ±1.26 % ripple** | `motor_results.Kt_N_per_kA` |
| Exit velocity, 3U | **16.537 m/s** | `motor_results.shot.v_exit` |
| Payload acceleration | **10.72 g** | `motor_results.shot.a_g` |
| Pulse duration | **157.3 ms** | `motor_results.shot.t_ms` |
| Peak current | **330 A** | `motor_results.shot.I_peak` |
| Bank sag | **5.19 %** | `motor_results.shot.sag_pct` |
| Energy drawn per shot | **2796 J** | `motor_results.shot.E_drawn` |
| Copper loss per shot | **828 J** | `motor_results.shot.Q_copper` |
| Payload kinetic energy | **547 J** | `motor_results.shot.KE_payload` |
| Electrical-to-payload efficiency | **19.6 %** | `motor_results.shot.eff_pct` |
| Closed-loop dispersion | **0.0271 m/s (3σ)** | `motor_results.closed_loop_3sigma` |
| Fleet setpoint | **16.2 m/s** | `motor_results.v_fleet_setpoint` |
| Sled mass | **9.45 kg (measured)** | `mass_properties.sled_kg` |
| Dry / loaded mass | **76.9 / 124.9 kg** | `mass_properties.dry_kg` |
| Lifetime multiplier, mean activity | **x1.62** | `astro_results.lifetime.mean` |
| Recoil per shot | **66.1 N·s** | `astro_results.recoil_Ns_per_shot` |
| Phase realignment period | **9.9 days** | `astro_results.conjunction.realign_days` |
| Energy closure | **100.0 %** | `sizing.energy_closure.closure_pct` |
| Track first mode | **109.0 Hz fixed-fixed** | `sizing.track_mode.fixed_fixed_Hz` |
| Recurring hardware cost | **₹1,348,655 per unit (all prices assumed)** | `cost.total_INR` |

## Change control

### What may move the baseline during Phase I

1. **Error correction.** A value that is wrong. P17, the inter-array attraction being 37 %
   high, qualifies, and stays Phase I even though correcting it moves three coupled numbers.
2. **A validation outcome against a band declared before its run.** This is how the baseline
   last moved: `validation/A4_sled_structural.md` fixed the consequence of each sled-mass
   outcome *before* the analysis ran, the measurement landed in the ≥ 6.80 kg branch, and the
   scripts followed the rule rather than a preference.
3. **A defect that makes a Phase I deliverable wrong.** A paper that states something the
   scripts contradict is a defect regardless of which is right.

### What may not

Performance improvement. Architecture change. Anything whose motivation is *better* rather
than *correct*. These go to [`docs/PHASE_II.md`](docs/PHASE_II.md) with an entry criterion,
and are reviewed at the next baseline boundary.

**The boundary is by type, not by convenience.** The momentum-transfer release in
`docs/DESIGN_OPTIONS_exit_velocity.md` recovers the entire velocity shortfall for 1.6 % of
shot energy and is the most interesting idea in this repository. It defers. P17 is tedious,
touches three coupled numbers, and improves nothing anyone will notice. It does not defer.
If that distinction ever bends toward whichever is easier, the baseline has stopped meaning
anything.

### Every baseline change must

- **Name its trigger**, which P-item, E-item or validation outcome forced it.
- **State which validations it invalidates.** This is the P19 lesson: moving the sled mass
  silently invalidated A5 and A8, both of which had been run at the old operating point. That
  was discovered afterwards. It should have been declared as a consequence at the time.
- **Propagate in order: scripts, then figures, then paper.** Never the reverse. The scripts are
  authoritative; `paper/make_figures.py` and `tools/make_baseline.py` regenerate from them.
- **Be recorded** in `CHANGELOG.md` and as an ADR under `docs/adr/`.

## Verifying this file

```bash
python3 tools/make_baseline.py    # regenerates; a clean diff means the baseline holds
git diff --exit-code BASELINE.md  # non-zero means the scripts have moved and the record has not
```

That second command is the useful one. If it ever fails unexpectedly, something changed a
script value without going through change control.

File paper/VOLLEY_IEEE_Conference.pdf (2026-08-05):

# VOLLEY: A Linear-Motor Electromagnetic Deployment System for Deterministic CubeSat Orbit Seeding from Small Launch Vehicles

Adityavardhan Mishra
Department of Mechanical Engineering, Symbiosis Institute of Technology Symbiosis International (Deemed University), Pune, India
PRN 23070125054

Abstract—Secondary payloads on rideshare missions inherit the orbit of the primary customer, and the spring deployers that release them impart 1–2 m/s, too little to alter that orbit in any useful way. This paper presents the design and analysis of VOLLEY, a magazine-fed electromagnetic deployer that ejects unmodified CubeSats at a programmable velocity an order of magnitude above spring systems while remaining within standard qualification loads. On-orbit electromagnetic launch of CubeSats has been studied before, at velocities twenty times higher but at accelerations of order 10³
g and with a conductive armature attached to the payload [27]; the contribution claimed here is not electromagnetic deployment as such but the combination of a programmable velocity with a satellite that is never modified and an acceleration inside its existing qualification envelope. An architecture trade selects an ironless double-sided Halbach-array linear synchronous motor driving a reusable permanent-magnet sled along a 1.5 m track, with twelve 3U satellites fed from two transverse cassettes, a contactless eddy-current arrest brake, and supercapacitor pulse power. A winding-resolved motor model, cross-checked against an independent magnetostatic computation, gives a thrust constant of 11.03 N per kA/m with ±1.0% ripple and an exit velocity of 16.4 m/s for a 3U payload at 10.5 g, drawing 2.85 kJ per shot. Regenerative braking of the reusable sled over 240 mm of stator downstream of release returns 0.29 kJ of the sled’s 1.27 kJ to the bank at the same sheet-current rating, giving 21.0% electricaltopayload efficiency net of recovery; the eddy brake remains necessary and still absorbs 0.93 kJ per shot. The velocity follows from a 9.4 kg sled mass computed from the detailed CAD solid volumes; an earlier parametric estimate of 4.9 kg gave 20.4 m/s, and the decision to adopt the CAD-derived value was fixed in advance of the structural analysis that tested it. Closed-loop simulation with realistic sensing yields a velocity dispersion of 0.027 m/s (3σ) about a 16.2 m/s fleet setpoint, equivalent to ±0.10 km of apogee placement. One maximum-velocity ejection multiplies a propulsion-less satellite’s orbital lifetime by 1.62; an independent propagator reproduced the earlier 20.4 m/s operating point at mean and high solar activity but not at low; the current 1.62 multiplier has not been independently rerun, so the ratio is quoted at a stated activity level and is not claimed invariant, and differential ejection velocities of 2–10 m/s establish 30◦
constellation spacing in 1.4–6.9 days against 25 days for differential-drag phasing under identical assumptions. The mass model closes the system at 76.5 kg dry and 124.5 kg loaded; its component lumps are not physical measurements. Host integration is developed generically for any restartable upper stage or hosted platform, with ISRO’s POEM and Skyroot’s Vikram-1 kick stage analyzed as candidate first hosts.
Index Terms—CubeSat deployment, electromagnetic launch, Halbach array, linear synchronous motor, rideshare, constellation phasing, small launch vehicles.
I. INTRODUCTION
The rideshare model has cut the cost of reaching orbit for small satellites, and it has done so by removing their choice of destination. A CubeSat manifested as a secondary payload is released wherever the primary customer’s mission ends, through a spring deployer whose 1–2 m/s separation velocity exists for clearance rather than for orbit shaping. Satellites that carry propulsion can correct for this. The large class that cannot, which includes most university missions and cost-constrained commercial payloads, remains wherever it was dropped, at whatever altitude and phasing the manifest happened to produce. That class is the majority: of the more than 4,800 nanosatellites and CubeSats catalogued as of January 2026, on the order of 222 carry a propulsion system [24]. The population is also still growing, with roughly 16,900 satellites under 500 kg forecast for 2026–2035, about a third of all satellites launched but only some 6% of launched mass [25]—so the constellation, whose members must be distributed before it functions as one, is now the dominant architecture by count while the deployment interface that separates them has not changed in twenty years.
Two families of hardware bracket the problem. Below it sit flight-proven springs, typified by the J-SSOD at 1.1–1.7 m/s
[2] and commercial deployers near 2 m/s [20]. Above it sit propulsive orbital transfer vehicles, which move an entire bus through hundreds of m/s at a cost, mass, and integration burden far beyond what a 4 kg satellite needing a 20 m/s nudge can justify. Between the two lies a regime unserved by flown hardware: no deployment system in service operates in the tens of m/s, although the astrodynamic utility of that band is substantial and quantifiable. The band is not unexamined in the literature. Feng et al. simulate an on-orbit three-stage induction coilgun accelerating a 20 kg CubeSat to 321.56 m/s and map the resulting reachable domain [27], and a sustained line of work from a second group develops magazine-fed electromagnetic transfer and release of stacked CubeSats, carried as far as a measured prototype of the transport mechanism [30], [28], [29]. The contribution claimed here is therefore narrower and specific: a programmable exit velocity delivered to an unmodified satellite within its own qualification envelope.

Both qualifiers do work. An induction coilgun accelerates a conductive armature, which must either be attached to the customer satellite or separated as a sabot. And the velocity such a machine makes available is bounded in practice not by the machine but by the payload: Feng’s 321.56 m/s is reached over a 3.9 m barrel, a mean acceleration of 1.35×10³ g, with a reported peak force above 600 kN on a 20 kg body—some 3 × 10³ g—against the 14 g quasi-static qualification level a standard CubeSat is built to [21]. That gap, not the achievable speed, is what confines useful exit velocity to the tens of m/s, and it is the constraint this design was built around.
This paper develops a system for that band and keeps the treatment deliberately host-agnostic: the deployer is specified against a generic interface that any restartable upper stage, kick stage, or hosted orbital platform can satisfy, and specific vehicles enter only as worked candidate examples. The contributions are (1) an architecture trade showing why a linear synchronous motor rather than a coilgun is the correct electromagnetic topology at CubeSat structural limits; (2) a complete system design covering magazine, restraint, arrest, power, and abort; (3) a winding-resolved electromagnetic model, independently verified, together with ten quantitative analyses spanning launch performance, astrodynamics, deployment safety, and host interaction; and (4) a generalized integration framework with capacity and recoil budgets evaluated for candidate hosts in the Indian launch ecosystem.

II. RELATED WORK

A. Deployment heritage
The P-POD established the rail-and-spring standard, and the ISS-based J-SSOD and NanoRacks systems industrialized it [2], [3]. The failure record is instructive: the NanoRacks ball-lock anomaly, in which jack-screw preload above 0.11 N·m drove the release mechanism toward seizure, traced to a load path in which ascent preload passed through the release device itself [1]. VOLLEY’s restraint architecture is designed against precisely this fault class. The closest electromagnetic relative is a proposed multi-CubeSat deployer using permanent-magnet conveying and ejection stages, demonstrated at 0.4–1.4 m/s [4]; VOLLEY extends the same Lorentz-force principle to roughly fifteen times that velocity.
B. Electromagnetic launch and supporting technology Coilgun research examined nanosatellite launch at km/s scales [5], [6], establishing contactless acceleration and its costs: the single-stage reluctance machines of that lineage convert 1–2% of stored energy into kinetic energy, though multi-stage induction designs do far better, and the on-orbit CubeSat launcher of [27] reports 14.9–19.9%. Ironless permanent-magnet linear machines occupy the opposite corner of the design space: the Halbach array concentrates flux on one working face [7], and the Inductrack program demonstrated large forces from such arrays with no iron and no sliding contact [8]. Space-qualified supercapacitors have progressed to an established supply chain through ESA-led programmes [9], [10]. Eddy-current dampers carry decades of flight heritage in deployment mechanisms [11]. On the astrodynamics side, Planet Labs demonstrated propulsion-free constellation phasing by differential drag over campaigns of weeks to months [12], [13]; that timescale is the benchmark against which impulsive seeding is measured. ISRO’s POEM programme converted the spent PSLV fourth stage into a stabilized hostedpayload platform across four missions, closing POEM-3 with a controlled, debris-free reentry [14], [15], establishing the regulatory template for operating equipment on a spent stage.

III. SYSTEM ARCHITECTURE
A. Requirements
The driving requirements are: eject an unmodified 3U CubeSat, imposing no armature, plating, or electrical interface on the customer satellite; keep payload acceleration within standard qualification loads (25–30 g); fit an ESPA-Grandeclass envelope and mass allocation, a requirement the current geometry does not yet meet (Sec. XV); provide per-satellite programmable velocity with dispersion small against its astrodynamic effect; carry a twelve-satellite manifest with autonomous sequencing; provide inhibits and a defined abort; and hand recoil to the host in a form its attitude control absorbs at negligible propellant cost.
B. Derivation of Principal Design Parameters
The values that define the machine are set by requirements and standards rather than chosen freely; Table I records the governing relation for each. Three deserve explicit statement. The acceleration ceiling follows from the CubeSat Design Specification qualification environment: NASA GEVS [21] protoflight random vibration integrates to 14.1 grms, whose 3σ envelope of roughly 42 g bounds the launch load, and a 25 g design cap preserves margin against it. An earlier version of this design was acceleration-limited: at a 4.9 kg parametric sled the ejection ran at 16.3 g, close enough to the cap that the cap set the velocity through vmax =

√
2amaxL. That is
no longer the binding constraint. With the sled computed at 9.4 kg from the CAD solid volumes the same commanded force accelerates a heavier moving mass, so the ejection sits at 10.5 g and the 1.3 m zone yields 16.4 m/s. The machine is now thrust-and-mass limited rather than acceleration-limited, with more than a factor of two of qualification margin left unused. Recovering velocity therefore means removing sled mass or raising sheet current, not shortening the stroke; a 0.2 m coast-trim zone completes the 1.5 m axis. Stroke buys velocity only as √
L, so the trade is unattractive: total track lengths of 1.0, 1.2, 1.5 and 1.8 m give 12.9, 14.4, 16.4 and 18.2 m/s respectively, and the envelope is already the binding packaging constraint (Sec. XV). The capacitor bank follows from the shot energy and the droop it actually reaches: at the 2.85 kJ draw the selected 6 F bank sags to V1 = 0.947V0, and

C =

2E
V

2
0 − V

2
1
= 6.00 F → 6 F, | (1)

realized as thirty-two series 190 F, 3 V commercial cells for a 96 V rail compatible with 1200 V SiC devices at a comfortable derating.

TABLE I
GOVERNING RELATION FOR EACH PRINCIPAL PARAMETER
Parameter | Value | Set by
Accel. cap | 25 g | GEVS 14.1 grms, 3σ [21]
Track length | 1.5 m | v =

√
| | 2aL + coast zone
Rail material | 7075-T6, hard anodize | CDS rail spec [23]
Bank voltage | 96 V | SiC 1200 V derated 60%
Bank capacitance | 6 F | droop eqn (2), ≤5% SoC sag
Sled magnets | N45SH | thermal × field (Sec. V-F)

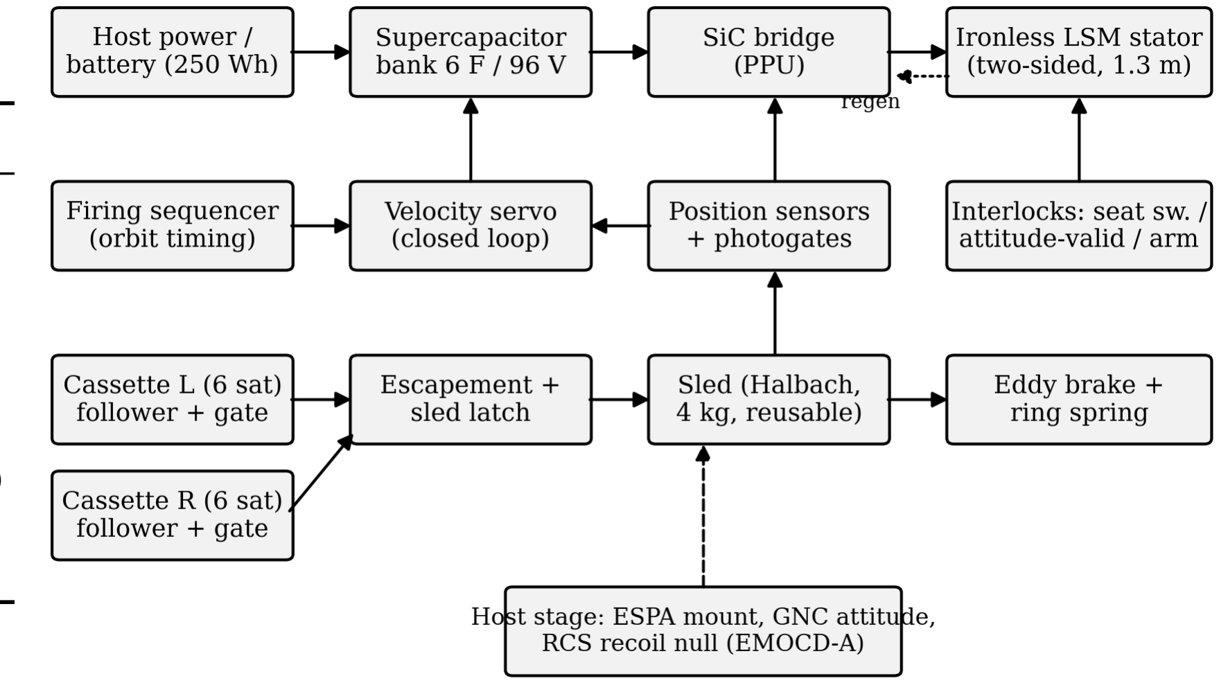
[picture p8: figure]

Brake cap | 200 g sled | magnet bond MoS (Sec. III-F)
Abort point | 45% stroke | braking-distance equality
Magazine | 12 (2×6) | cassette CoM symmetry

TABLE II
TOPOLOGY TRADE AT CUBESAT STRUCTURAL LIMITS
Criterion | Reluctance coilgun | Ironless LSM + sled
Velocity ceiling (payload-limited) | 26–35 m/s | 26–35 m/s

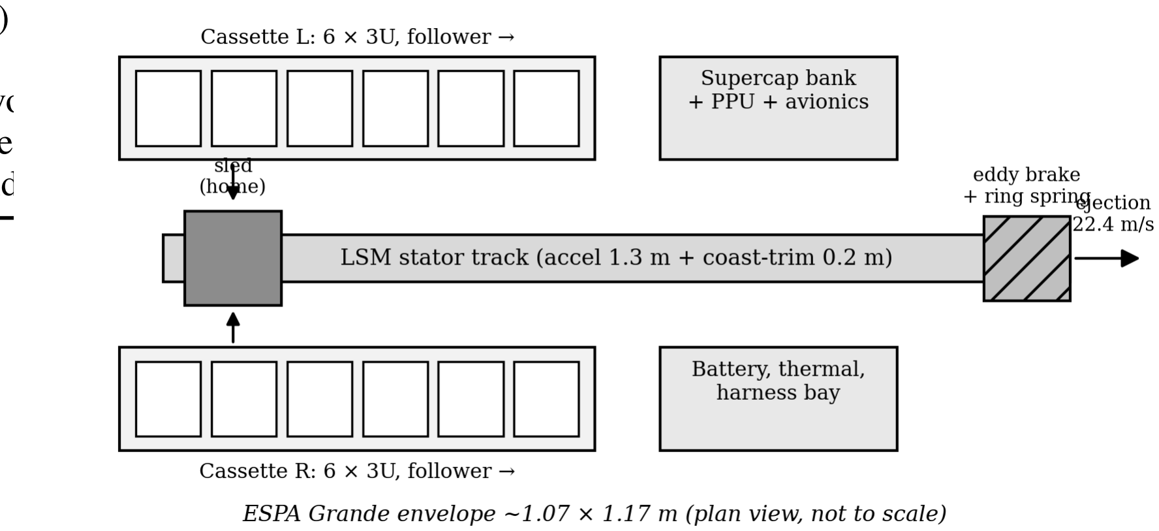
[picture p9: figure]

Electrical→payload efficiency | 14.9–19.9% [27] | 21.0% (Sec. V)
Satellite modification | armature required | none
Velocity control | pulse timing | closed-loop servo
Abort | none once fired | to ∼45% stroke
Field on stored satellites | pulsed, unshielded | Halbach self-shielded
C. Topology Trade
The payload settles the trade before the electromagnetics do. Exit velocity is bounded by

vmax =

p
2 amaxL, | (2)

so at 25–30 g over a 1.3–2 m stroke the ceiling is 26– 35 m/s. The coilgun’s defining advantage, a km/s-class ceiling, is unreachable by the payload it would carry, while its costs remain: microsecond timing against the suck-back effect, an armature bolted to the customer’s satellite, and no abort once fired. Efficiency is deliberately not among them: at 14.9– 19.9% [27] a multi-stage coilgun is comparable to the figure reported here, and an earlier version of this argument claimed otherwise on the strength of a single-stage number. A linear synchronous motor concedes nothing in the reachable envelope and inverts every cost: high drive efficiency, continuous servo control, and a reusable sled that carries the magnets so the satellite carries nothing. Table II summarizes.

D. Layout and Firing Cycle
The launcher is organized around a single 1.5 m track: a 1.3 m acceleration zone and a 0.2 m coast-and-trim zone (Figs. 1 and 2). The stator is an ironless double-sided three-phase copper winding; the mover is a 9.445 kg sled carrying opposed Halbach arrays (48 mm wavelength, 8 mm N45SH blocks, four blocks per wavelength) across a 12 mm winding gap. Two transverse cassettes of six 3U satellites flank the breech. The cycle: a follower advances one pitch and slides a satellite laterally onto the sled cradle (a subnewton operation in microgravity); a detent latch engages; a two-finger escapement retains the next satellite; the motor accelerates the stack; force is removed in the coast-trim zone where the servo makes its final correction; the sled enters

Fig. 1. System block diagram: power, control, mechanism, and host-interface chains.

Fig. 2. Plan-view layout against an ESPA-Grande-class envelope (not to scale). The closed envelope currently exceeds that class in length; see Sec. XV.

the brake and decelerates while the satellite departs along guide extensions. Retention during acceleration costs nothing, since inertia presses the satellite into the aft backstop, and release costs nothing, since braking the sled is the release. Internal mass motion produces transient counter-rotation, not a residual rigid-body rate after the mass stops. The corrected A13 budget gives a peak return rate of 0.136 deg/s for the assumed 500 kg host and 0.443 deg/s at 200 kg, so its two declared peak-rate bands remain failed. The ideal rigid-body residual is zero, and the previous 8.2 s rate-null and 18.1 s cadence floor are superseded. The motion instead leaves an attitude offset—0.42 deg in the 500 kg example under the assumed 166 mm lever arm—whose restoration time depends on a controller and schedule not modelled here. Structural ringing is also unmodelled. The repository still carries 10–20 s and 1200 s inter-shot assumptions; that ConOps contradiction remains open.

E. Restraint, Inhibits, and Abort

Launch restraint separates the preload path from the release path, the inverse of the NanoRacks fault [1]. One-shot retention gates at each cassette exit carry ascent preload directly into structure; the escapement is caged during ascent; the sled is held by a motorized over-center cam lock. Firing requires a three-inhibit chain: redundant seat switches, an attitude-valid flag from the host, and a sequencer arm. Abort is available to approximately 45% of the stroke, beyond which braking distance for the combined mass exceeds remaining track; the muzzle buffer is sized to capture an aborted combined mass. The retention gate carries the ascent preload of a six-satellite stack, 24 kg × 25 g = 5.9 kN, through two D6 A-286 shear pins (double-shear capacity 18.2 kN, margin 1.2 on ultimate at a 1.4 design factor); the escapement, caged behind the gate, sees none of this. The abort threshold is where the sled braking distance under the same thrust equals the remaining track, which for the loaded 13.4 kg carriage falls at 45% of stroke and 11.1 m/s. The commit fraction is unchanged by the heavier sled—braking distance and travelled distance scale with mass identically, so the mass cancels—but the velocity at the commit point falls with the acceleration.

F. Arrest, Power, and Materials
The sled leaves release with about 1.27 kJ. Motor regeneration alone cannot arrest it, because braking force is bounded by the same thrust constant as acceleration; that bound sets what regeneration can and cannot do, and both halves matter. Braking at the rated sheet current over the 240 mm of stator the closed envelope allows downstream of release extracts 334 J of mechanical work for 15 J of copper, returning 291 J to the bank, and the sled still reaches the brake at 14.1 m/s carrying 935 J. A copper-fin eddy-current brake therefore provides bulk arrest: force proportional to velocity, contactless, with flight heritage in the damper class [11]. Authority is abundant, so the pole entry is tapered to cap sled deceleration near 200 g. This limit is set by the magnet retention: a 65 g Halbach block at 200 g loads its bonded interface (10.8 cm²
) to only
0.12 MPa against a conservative 10 MPa epoxy allowable, a margin of 84, so 200 g is a deliberate conservatism protecting the brittle sinter rather than a strength limit. The 0.344 kg copper fin absorbs the sled’s residual 935 J per shot at an adiabatic 7.1 K per-shot transient rise; cooling between shots has not been modelled; a ring-spring catches the residual below 1.5 m/s (Fig. 3). Pulse energy comes from a 6 F, 96 V supercapacitor bank switched by a SiC bridge [9]. Materials follow three rules: nothing conductive rides the changing field (titanium sled chassis, PEEK formers), nothing near the track is ferromagnetic except by design (BeCu springs, A-286 fasteners), and nothing outgasses near customer optics (E595-compliant polymers, dry films, sealed roller cartridges).

IV. MODELS AND VERIFICATION

A. Field Model and Independent Verification
The Halbach airgap field is a decaying wave, B(y) = B0e

−ky with k = 2π/λ, summed over the two opposed faces. Because this carries the force budget, it was checked against an independent magnetostatic computation (analytic cuboid superposition, magpylib), with the array rotation-sense convention determined empirically by probing a single array on both faces; the exercise caught two successive sign errors whose outputs matched single-array fingerprints. Converged results: single-array mid-gap 0.351 T against the wave model’s

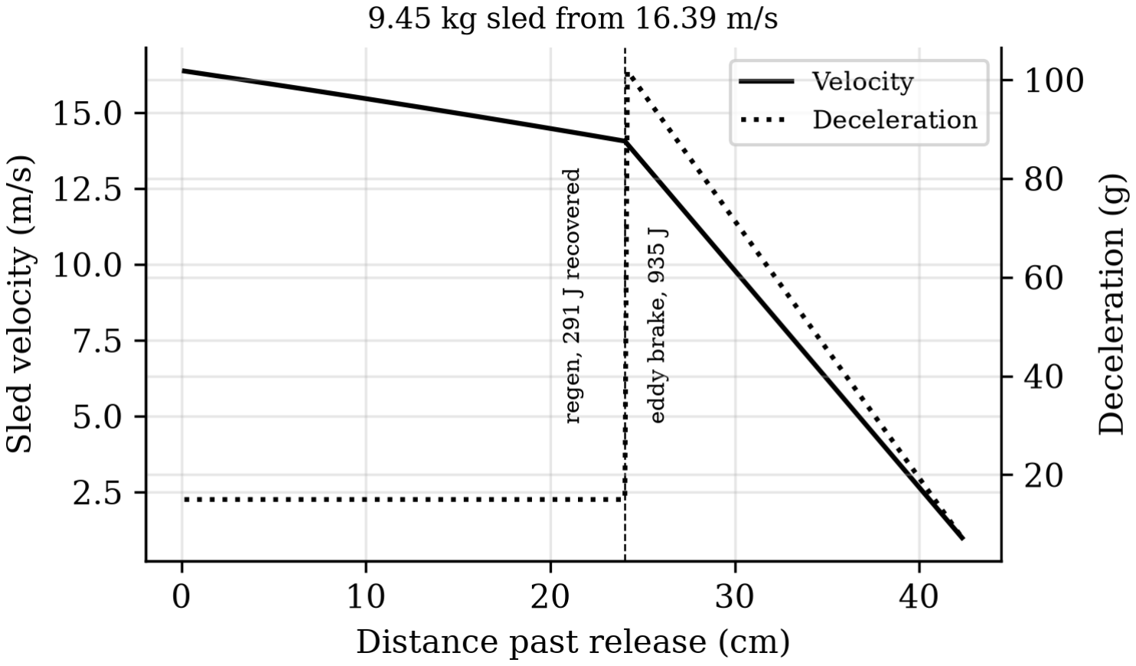
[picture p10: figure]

Fig. 3. Eddy-brake arrest, taper-limited to 200 g on the sled.

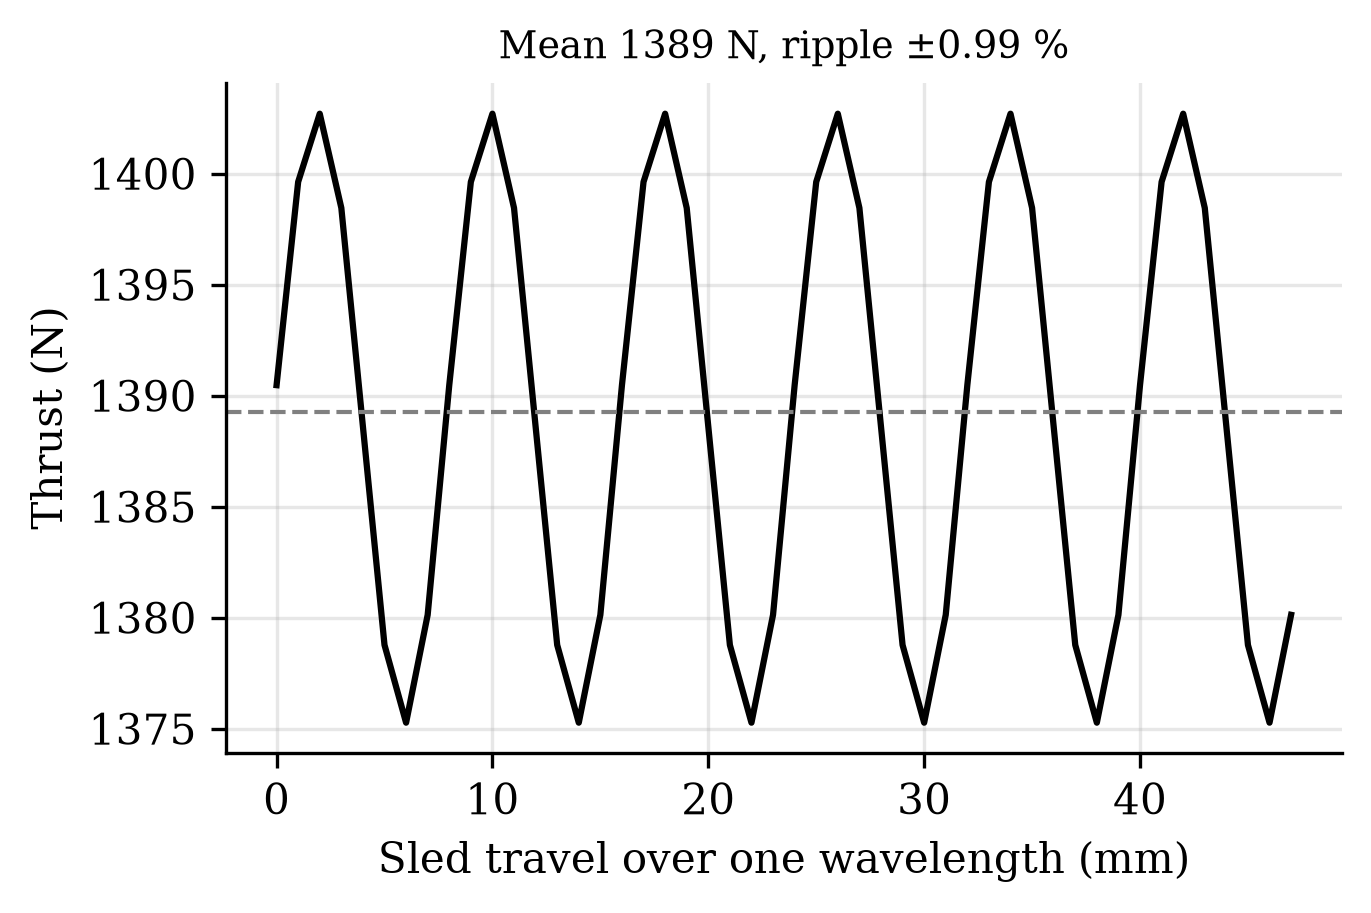
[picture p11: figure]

Fig. 4. Winding-resolved thrust over one wavelength of sled travel.

0.351 T; double-sided mid-gap peak 0.694 T against a predicted 0.702 T. The stray field behind the array back face, which sets the magnetic keep-out for stored satellites, computes to 22.7 mT at 10 mm, 4.3 mT at 20 mm, and 0.4 mT at 50 mm.

B. Winding-Resolved Thrust Constant
A slotless three-phase belt winding (pole pitch λ/2, belts of λ/6, winding factor 0.955) was resolved against the verified field by direct Lorentz integration with position-locked sinusoidal commutation, the field translated with the sled. The result is a thrust constant

Kt = 11.03 N per kA/m, ripple ±0.99% (6th harmonic), (3)

shown in Fig. 4. Synchronous extraction carries the onehalf traveling-wave factor that lumped ⟨B⟩KA models hide; the corrected constant is recovered operationally by rating the sheet current at 140 kA/m and commanding 126 kA/m (21 A/mm² pulse-only in the copper), where adiabatic heating remains 0.3 K per 159 ms shot.

C. Shot, Servo, and Astrodynamic Models

The shot integrates sled-plus-satellite dynamics against the supercapacitor circuit with explicit copper loss and a 95% converter. Velocity control uses a position-scheduled profile with proportional correction and a coast-trim residual correction from photogate measurement; an 800-run Monte Carlo over thrust-constant, mass, force-ripple, and sensor tolerances gives the dispersion. Orbital lifetime uses per-revolution orbitaveraged decay (Gauss tangential equations, quadrature over eccentric anomaly, static exponential atmosphere at mean activity [17]); the method was cross-validated against an independent Cowell RK4 propagation with drag, the two agreeing on 30-day semi-major-axis decay to 99.4%. Constellation seeding uses ∆a = 2a ∆v/v and the resulting period difference; deployment safety propagates the stage and all deployed ellipses with Kepler-plus-secular-J2 motion for 30 days, with candidate minima refined at 0.25 s sampling.

V. PERFORMANCE RESULTS
A. Launch Performance
At the rated point (3U reference, 9.445 kg sled computed from the CAD solid volumes, 1.3 m acceleration): exit velocity 16.4 m/s at 10.5 g, pulse 159 ms, peak current 339 A, and bank stateofcharge sag 5.3% (Fig. 5). Energy drawn is 2.85 kJ per shot, with copper heat of 835 J and a further 83 J dissipated in the bank’s own series resistance. Regenerative braking returns 291 J after release, so the net draw is 2.56 kJ. The payload receives 537 J, a 21.0% electricaltopayload efficiency; the sled’s share is split between 291 J recovered and 935 J dissipated in the arrest brake. Efficiency falls with the heavier sled for two compounding reasons: a larger fraction of the same mechanical work goes into a mass that is then braked away, and the longer 159 ms pulse accrues more copper loss at unchanged current density. Recovery is what partially offsets the first of those, and it is bounded by geometry rather than by loss: over the available 240 mm the braking pulse lasts 15.8 ms and burns 15 J of copper, against 835 J over the 159 ms shot, so recovered energy rises monotonically with braking force up to the winding’s rating and with distance beyond it. A 500 mm section would return 570 J and a 1 m section would arrest the sled outright while returning 783 J, but the closed envelope already exceeds its target class by 44% (Sec. XV), so distance is not available here. Peak current during recovery is 219 A, below the shot’s own 339 A, so the drive is not re-rated. The closed-loop Monte Carlo returns a dispersion of 0.027 m/s (3σ) at a 16.2 m/s fleet setpoint (Fig. 6), dominated by the sensing chain rather than plant tolerances. The setpoint must sit below the open-loop ceiling for the servo to retain authority; at 98.85% of it, the nominal headroom is 0.188 m/s. Table III gives the payload family: the system is force-limited above 1U, so heavier payloads trade velocity, never structural margin, and the deployer mass each customer pays for varies by a factor of thirty across the family (Sec. V-B).
B. Payload Class and the Mass-per-Satellite Argument Table III is read most usefully from its last column rather than its first. Exit velocity is nearly flat across the family, because the 9.445 kg sled is most of the moving mass: removing the payload entirely buys 19% of velocity, so velocity is a property of the sled and the stroke and not of the customer. Shortening the magnet array does not recover it either, since array length sets thrust and sled mass together—a 150 mm


Fig. 5. Shot profile at the rated point: (a) velocity with coast-trim zone; (b) bank voltage and current.

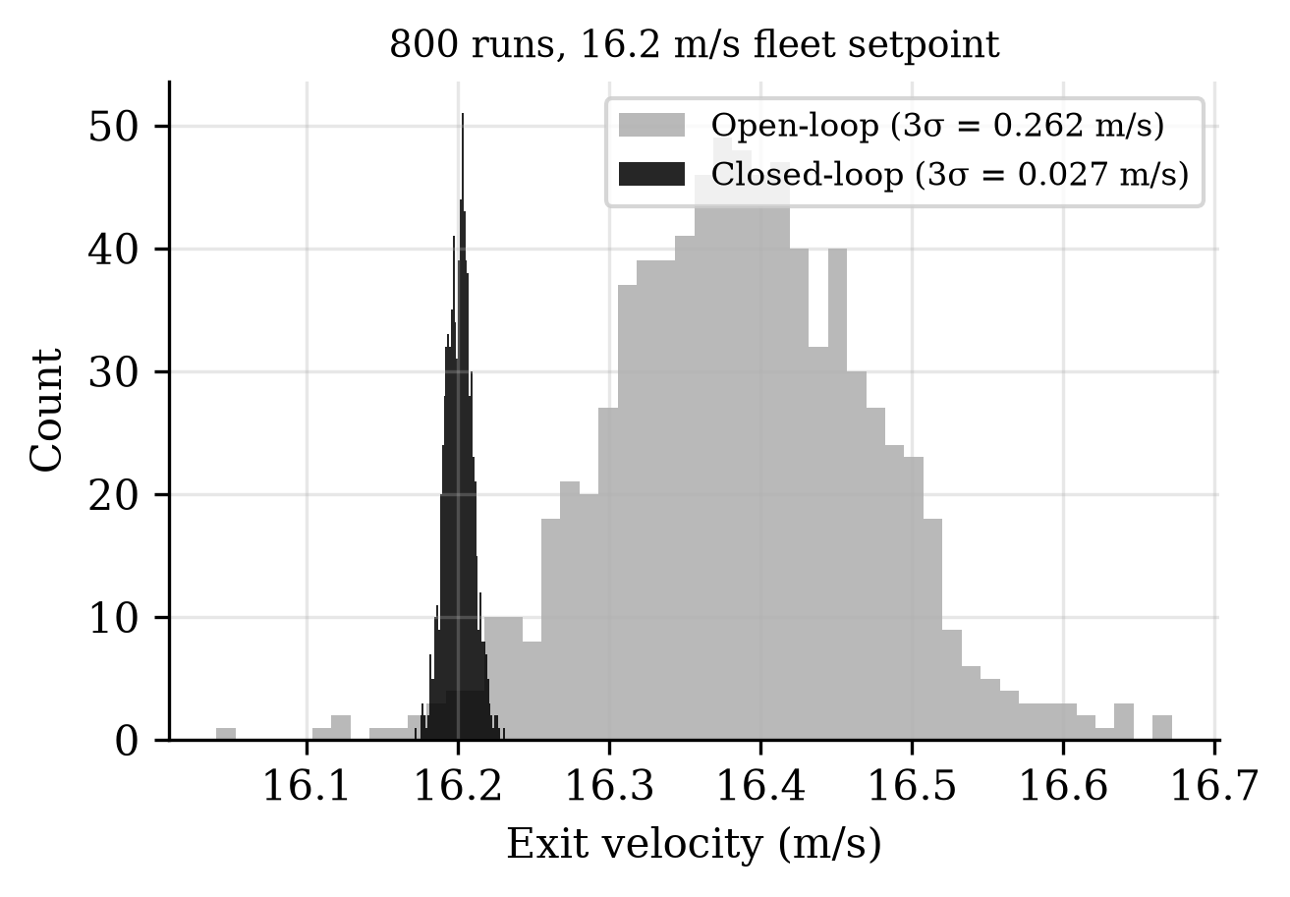
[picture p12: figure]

Fig. 6. Closed-loop exit-velocity dispersion, 800 Monte Carlo runs.

array gives a 5.15 kg sled but a 4.95 N per kA/m thrust constant, and the 3U case falls to 13.3 m/s.
The column that does move is deployer mass per satellite, by a factor of thirty. At 3U the machine spends 6.38 kg of deployer per customer, which loses to a cold-gas propulsion module delivering the same 16.4 m/s at 0.5–1.2 kg by roughly a factor of eight. At PocketQube it spends 0.24 kg and wins by two to five. The comparison inverts entirely on payload class, and on no machine parameter at all: not the thrust constant, not the stroke, not the sheet current.
Three qualifications belong with those counts rather than beneath them. First, they are volumetric. The packing efficiency is calibrated against the one configuration that has been laid out in CAD—the 3U case, where a raw volume ratio predicts 21 and the magazine holds 12—and the resulting 56% is then applied to classes for which no cassette exists. Second, the feed engages the CubeSat Design Specification cornerrail interface at the cradle, the escapement and the retention gate; PocketQubes, ThinSats and TubeSats do not have that interface, so a smaller class needs its own cassette, cradle and gate, which is mechanical design rather than a parameter change. Third, hundreds of satellites per load is a different machine from twelve: the campaign thermal case, the bank recharge duty and the escapement cycle life were all sized for twelve shots, and the bank is already the binding constraint at that number (Sec. XV). What Table III establishes is that payload class dominates the economic argument, not that a small-payload variant has been designed.

TABLE III
PAYLOAD FAMILY AT THE RATED POINT (1.3 M ACCELERATION, 9.445 KG CAD-DERIVED SLED). DEPLOYER MASS PER SATELLITE USES THE 76.5 KG DRY MASS AND A PACKING MODEL CALIBRATED SO THE 3U CASE

RETURNS THE TWELVE THE MAGAZINE IS LAID OUT FOR

Class | Exit vel. | Accel. | Per load | kg/sat.
PocketQube 1P (0.25 kg) | 19.5 m/s | 14.9 g | 326 | 0.24
ThinSat (0.28 kg) | 19.4 m/s | 14.8 g | 123 | 0.63
PocketQube 3P (0.75 kg) | 19.0 m/s | 14.1 g | 108 | 0.71
TubeSat (0.75 kg) | 19.0 m/s | 14.1 g | 41 | 1.88
1U (1.33 kg) | 18.5 m/s | 13.4 g | 40 | 1.92
3U (4 kg) | 16.4 m/s | 10.5 g | 12 | 6.38
6U (8 kg) | 14.5 m/s | 8.3 g | 6 | 12.82
12U (12 kg) | 13.1 m/s | 6.7 g | 3 | 25.63
C. Astrodynamic Utility

A prograde ejection raises apogee while leaving perigee at the deployment altitude, so the correct claim is a longer-lived ellipse. At 450 km with ballistic coefficient 61 kg/m²
, one
16.4 m/s shot multiplies lifetime by 1.62 at mean solar activity (base lifetimes 0.52–2.61 yr across the activity range; Figs. 7 and 8).
An earlier version of this work claimed the multiplier was invariant to two decimal places across ballistic coefficients of 40–90 kg/m²
and across a fivefold density range, and offered that invariance as the result the analysis could defend. That claim does not survive an independent propagator. Run headless against MSISE90 with 20×20 gravity, lunisolar third bodies and solar radiation pressure, GMAT R2022a reproduces the multiplier at mean and high activity but returns 2.07 at low activity, a spread of 18% against a 5% acceptance band fixed before the run. The reason is a defect in how the sweep was posed rather than in the arithmetic: the model represents solar activity as a uniform multiplicative scale on density, and ballistic coefficient enters the drag term in the same multiplicative slot, so both sweeps divide the two lifetimes being compared by the same factor. Their ratio cannot move, whatever the atmosphere does. A real atmosphere changes the shape of the density–altitude profile with activity, the boosted orbit’s apogee samples that profile some 37 km higher than the baseline’s, and the ratio then does move. The multiplier is therefore quoted here at a stated activity level, and no invariance is claimed.
Differential ejection velocities put adjacent satellites on different periods: splits of 2, 5, and 10 m/s reach 30◦ spacing
in 6.9, 2.8, and 1.4 days. Under identical density and geometry assumptions, differential drag between 3:1 area configurations achieves the same spacing in 25.0 days (Fig. 9), consistent with flown drag-phasing campaigns operating over weeks to months [12]. Impulsive seeding followed by drag trim follows naturally as a hybrid.
D. Deployment Safety

Every prograde shot leaves an ellipse whose perigee sits at the firing altitude, so the fleet re-crosses the stage’s orbit by construction, and the along-track phase between a deployed


Fig. 7. Orbital lifetime vs deployment altitude (BC = 61 kg/m² , mean
activity).

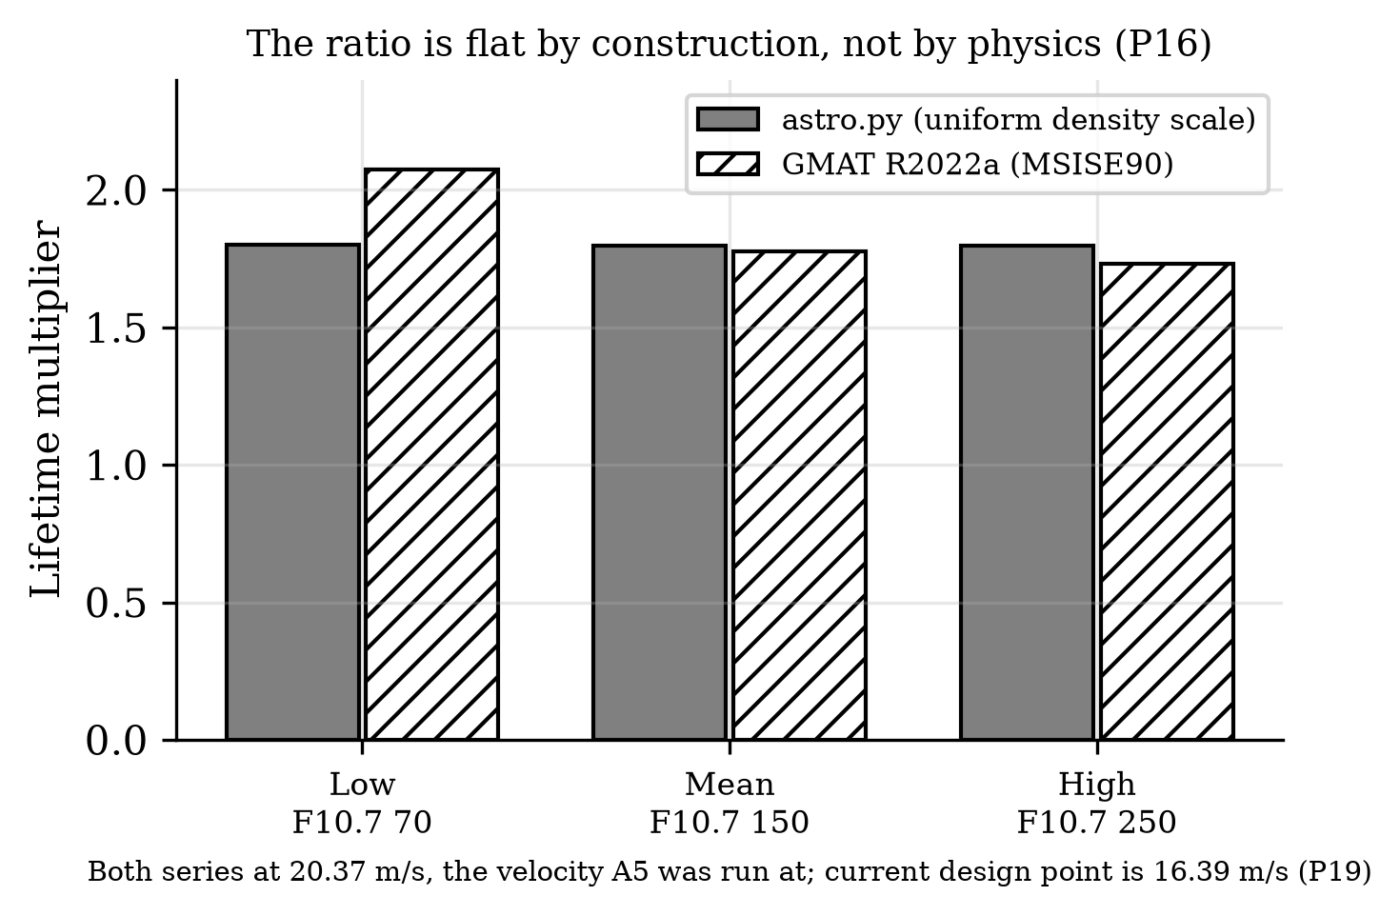
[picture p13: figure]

Fig. 8. Solar-activity sweep against GMAT. The static-atmosphere model returns a flat ratio by construction, not by physics; an independent propagator does not.

satellite and the stage realigns on a period of 9.9 days at the rated velocity (Fig. 10). The closest approach reached within a 30-day screening window is deliberately not quoted here as a safety figure: because both bodies re-cross the same altitude, that minimum is fixed by the exact along-track phase at crossing, which is acutely sensitive to ejection velocity— in the model a ±2.5% change about the rated point sweeps the 30-day minimum by more than an order of magnitude. It is a near-resonant sample of the beat geometry, not a design property. Two statements survive that sensitivity and carry the safety argument. First, per-shot collision-avoidance (COLA) screening is mandatory for every ejection, because the approach geometry cannot be certified from the nominal velocity alone. Second, disposing of the host stage before the first 9.9-day realignment—routine for a restartable stage— removes the recurring close-approach mechanism at its source, before the fleet can return to the stage’s along-track position. Per-shot conjunction products remain a mission-operations deliverable.

E. Error, Tip-Off, and Mass
The 0.027 m/s dispersion maps to ±0.10 km apogee placement at 450 km: sub-kilometre deterministic insertion for a satellite with no propulsion. The analytic tip-off budget sums to 3.9 deg/s worst case, which exceeds the tighter 2 deg/s comparator adopted for A7; the release transient has not yet

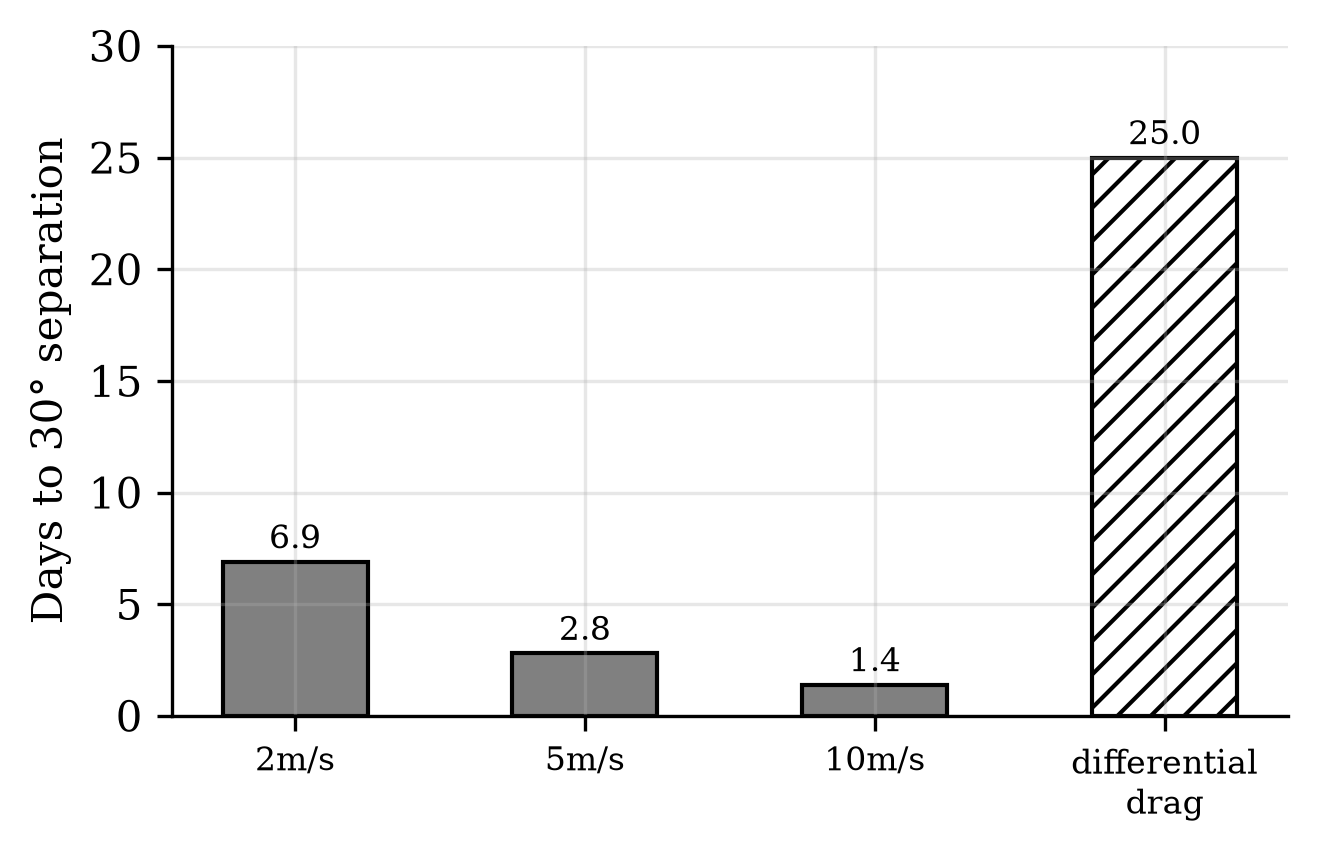
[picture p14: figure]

Fig. 9. Constellation seeding: VOLLEY velocity splits versus differential drag under identical assumptions.

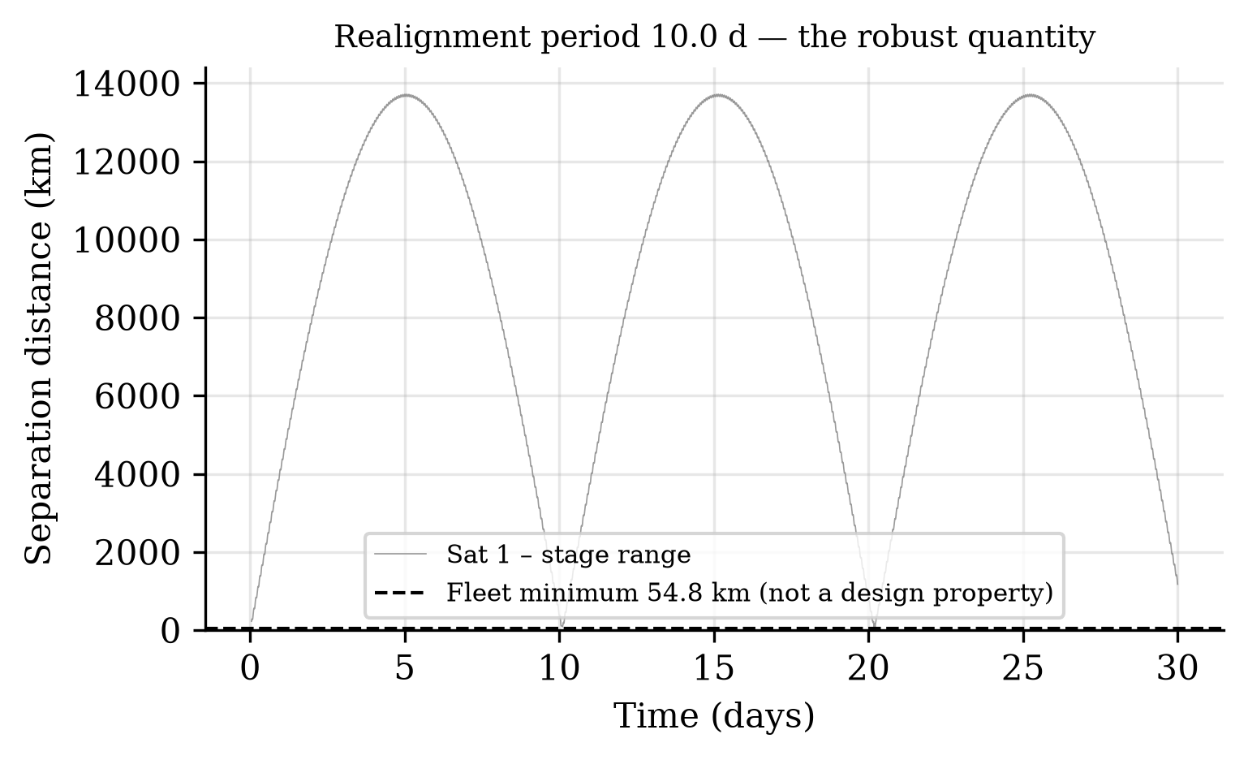
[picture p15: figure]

Fig. 10. Satellite–stage range over 30 days, staggered firing at the rated velocity.

been run in the declared multibody validation, so this remains a failure against the comparator rather than a closed result (Fig. 11). Recoil per shot is the satellite’s momentum only,

### 65.6 N·s, the sled’s share returning through the brake. The

solid model closes dry mass at 76.5 kg (loaded 124.5 kg, centre of gravity 0.44 m from the breech), with the ironless stator at 7.3 kg of copper and formers; the system uses roughly a third of an ESPA Grande mass allocation. It does not currently fit the corresponding envelope: the closed CAD assembly spans 1839 mm along the track against the roughly 1270 mm of that class, because the arrest brake sits beyond the release point and the enclosure must span it. Resolving this means shortening the track, repackaging the brake, or accommodating on a host that does not impose the ESPA-Grande envelope; it is an open packaging item, not a solved one.

VI. GENERALIZED HOST INTEGRATION

A. Interface Requirements for Any Host

VOLLEY-A, the attached mode analyzed here, requires four things of a host: a secondary-payload-class mechanical mount; 150–300 W of recharge power or an equivalent battery allocation; an attitude reference and enough control authority to null per-shot torque; and a disposal path consistent with debris rules. Nothing in the design binds it to one vehicle. Two

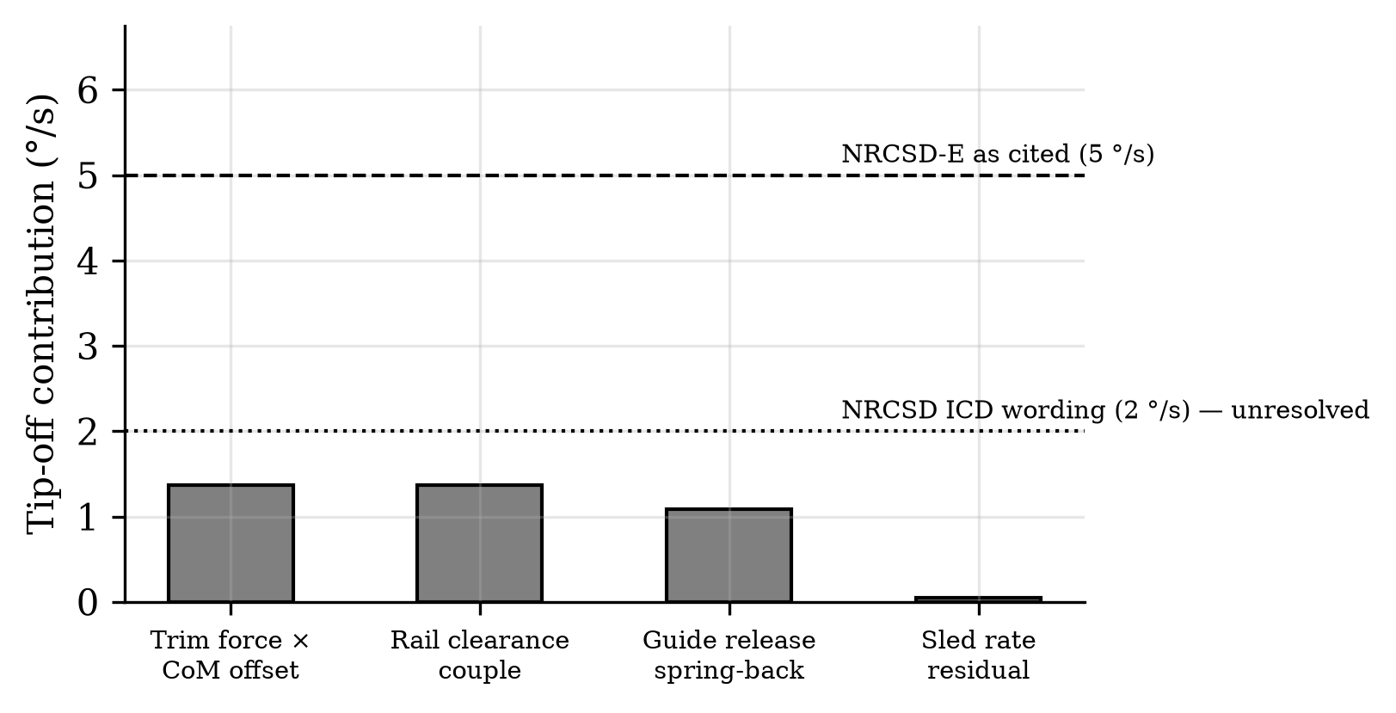
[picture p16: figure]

Fig. 11. Tip-off error budget against deployer requirement classes.

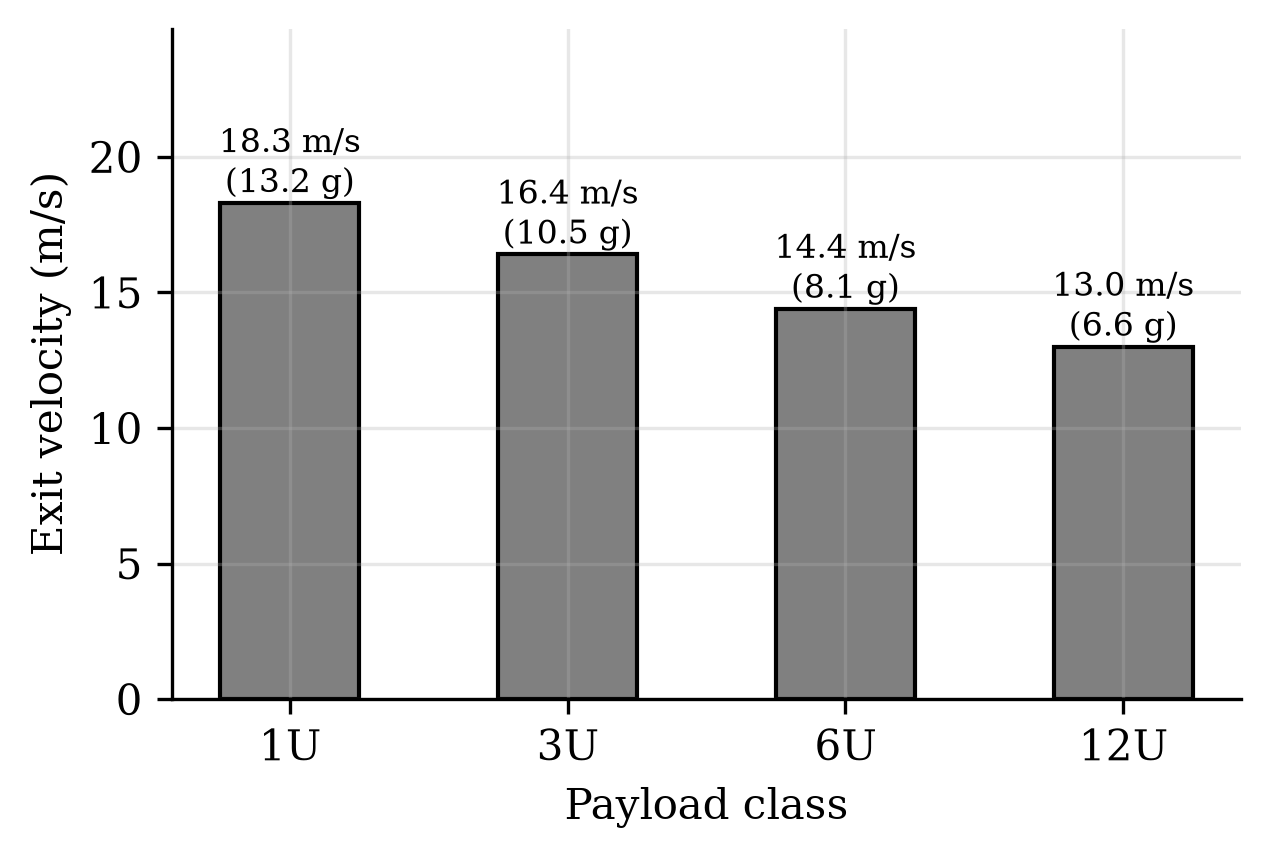
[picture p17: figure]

Fig. 12. Payload family: force-limited above 1U; velocity, not safety, is traded.

recoil facts generalize across hosts. First, correction propellant depends only on total ejected momentum, 0.787 kN·s for a full manifest, about 0.37 kg of hydrazine-class propellant regardless of host mass; host mass sets the per-shot rate disturbance, not the fuel bill. Second, the per-shot translation scales inversely with host mass (Table IV) and, for restartable stages, folds into disposal targeting. VOLLEY-F, a free-flyer variant with its own GNC, is the growth path for multi-day firing geometry and is not analyzed further here.

B. Candidate Hosts
Any restartable kick stage, extended-mission upper stage, or hosted orbital platform satisfies the interface. Two Indian candidates are worked as examples because both exist today. ISRO’s POEM is the flown precedent: a spent PS4 operated as a three-axis-stabilized hosted platform with solar power, NavIC navigation, and helium attitude thrusters, retired by controlled reentry [14], [15]; it supplies everything VOLLEY-A borrows, and its zero-debris closeout is the regulatory template. Skyroot Aerospace’s Vikram-1 carries a restartable liquid Orbit Adjustment Module (one Raman-2 engine, four Raman Mini thrusters, eight cold-gas thrusters, stage-tested through more than a thousand pulses [18]) whose stated multiorbit deployment role is functionally the PS4’s; against the vehicle’s published 350 kg LEO capacity [19], a loaded VOL-LEY is 34%, falling to 22% and 13% on the announced 550 kg and 900 kg family members, so early flights are dedicated demonstrations and later ones ordinary manifest items. One integration quantity cannot be closed from public data: the OAM’s mass and control authority are undisclosed [18], which

TABLE IV
PER-SHOT RECOIL (65.6 N·S) VERSUS HOST CLASS
Host class | ∆V per shot | 12-shot total
200 kg free-flyer | 328 mm/s | 3.93 m/s
300 kg kick stage | 219 mm/s | 2.62 m/s
600 kg kick stage | 109 mm/s | 1.31 m/s
900 kg (PS4 class) | 72.8 mm/s | 0.87 m/s
420 t (station class) | 0.2 mm/s | 2.3 mm/s

is why Table IV is parametric; obtaining stage mass, thruster impulse budget, and coast duration is the single data exchange that converts the analysis from parametric to specific for any candidate vehicle, Indian or otherwise. Comparable hosts elsewhere include kick stages evolved into mission platforms and ESPA-hosted propulsive rings; the interface asks the same four questions of each.

C. Integration Interfaces
The four-item interface resolves into concrete provisions. Mechanically the deployer bolts to a standard ESPA or ESPA-Grande ring through a canted bracket that passes the thrust line near the host centre of mass; the interface control document fixes the bolt pattern, envelope, and the published magnetic keep-out radius. Electrically it draws a 150–300 W recharge feed and a switched safety-inhibit line, with an isolated 28 V or bus-compatible tap and a dedicated ground per launch-vehicle EMC practice. The command interface is a serial link over which the host passes state vector and attitude-valid flags and the deployer returns telemetry: bank voltage, per-slot seat status, sled position, and shot confirmation. Sequencing is autonomous within a host-authorized window, the deployer computing each firing time from the supplied state and requesting only an attitude hold and the recoil-null authority quantified in Table IV; fault handling hands control back to the host safe-state on any inhibit trip. This division, deployer owning the firing logic and the host owning attitude and disposal, is what lets the same unit integrate on any compliant stage with only the electrical and command taps re-qualified per vehicle.
D. Position in the Deployment Landscape
Deployment services today form two tiers: flown lowvelocity springs (EXOpod-class hardware near 2 m/s with hundreds of deployments [20]) and announced propulsive transfer vehicles offering hundreds of m/s to whole buses, none yet flown in the small-OTV class relevant here [26]. VOLLEY does not compete with either on its own terms: it cannot change a plane, and a spring cannot place twelve satellites on twelve chosen ellipses. Table V states the comparison. The middle tier, per-satellite deterministic velocity at deployerclass mass serving the propulsion-less payload population, currently has no demonstrated occupant.
E. Demonstration Path
The programme is ground-testable to an unusual degree: a full-scale 1.5 m track firing a mass simulator into the eddy

TABLE V
SERVICE TIERS FOR SMALL-SATELLITE ORBIT PLACEMENT
Attribute | Spring deployer | VOLLEY (this work) | Transfer vehicle
Velocity authority | ∼2 m/s fixed | 2–20 m/s programmable | 100s m/s
Per-satellite targeting | no | yes, ±0.027 m/s | yes
Satellite modification | none | none | rides as payload
System mass, 12×3U | 10–20 kg | 125 kg loaded | 100s kg + prop.
Plane/LTAN change | no | no (≤0.2◦
| | ) | yes
Flight status | flown, extensive | design study | announced

TABLE VI
FIRST-ORDER SENSITIVITIES AT THE RATED POINT
Variable | Affects | Sensitivity
Payload mass | v | − ¹
| | 2 (%/% of mtot)
Magnet remanence Br | F, v | +1.0, +0.5 %/%
Current density | F, v | +1.0, +0.5 %/%
Winding resistance | η | −0.15 %/%
Capacitor ESR | sag | +0.04 V/mΩ
Gap asymmetry | Kt | −13 %/mm
Sensor noise (8 mm/s) | dispersion | sets 3σ floor
Temperature (Br) | Kt | −0.11 %/K

brake, with the complete feed cycle, sits within a university laboratory budget and converts the velocity, dispersion, and tip-off claims into measured quantities. The flight step is a captivecarry demonstration, full sled cycles with a payload never released, requiring no deployment approvals while gathering the reaction-load and servo data that certify the firing event; any hosted platform of the POEM class serves.

VII. SENSITIVITY AND UNCERTAINTY
Because several inputs carry manufacturing or environmental spread, the rated point is bracketed by a first-order sensitivity analysis (Table VI). Each coefficient is the local partial derivative of exit velocity or thrust with respect to the listed variable, evaluated at the rated point. The dominant contributors are payload mass and magnet remanence; the velocity model is mild in all of them, and the closed-loop servo further collapses the delivered dispersion to 0.027 m/s (Sec. V-
A) because it commands current against measured position rather than trusting the plant. Root-sum-square combination of the manufacturing terms (magnet grade ±2%, gap ±0.05 mm, resistance ±5%, ESR ±20%) gives an open-loop velocity spread of ±2.1%, consistent with the Monte Carlo of Fig. 6. Environmental terms are handled by rating margin: the N45SH remanence temperature coefficient of −0.11%/K over a ±40 K operating band moves the thrust constant by ∓4.4%, so the worst-case cold-to-hot requirement of 132 kA/m stays inside the 140 kA/m current rating without re-tuning. Atmospheric and solar-activity spread do not affect the machine and enter only through orbital lifetime, where Sec. V-B records that the sweep previously offered as evidence of invariance could not, by construction, have detected a change.

VIII. MECHANICAL ANALYSIS
The structural load path is sized to the two governing cases: launch vibration during ascent and the arrest impulse during operation. Fastener and pin margins are quoted on ultimate strength at a 1.4 design factor per common launch-hardware practice, consistent with the qualification philosophy of GEVS
[21] and ECSS structural standards [22].

Track stiffness. The dominant flight requirement is a first natural frequency above the launch-vehicle primary band, conventionally 70–100 Hz for secondary structure. Modeling the twin-longeron track as a uniform beam carrying the 20 kg stator distributed mass, the fundamental is f1 = (λ

2

1/2πL²
)

p
EI/µ with EI from two 7075 box sections. A simply-supported idealization gives 48 Hz, but bracketing both ends into the ESPA ring (fixed-fixed) raises the first mode to 109 Hz, clearing the requirement; the design therefore specifies end-fixed mounting with an intermediate rib.

Inter-array attraction. The two Halbach faces attract across the gap with a Maxwell stress p = B²/2µ0 ≈ 120 kPa at the 0.55 T mean working field, or 3.7 kN over the array footprint. Carried as a bending load into the titanium side plates, this produces 33 MPa against the 880 MPa Ti-6Al-4V yield, a margin above 20; the attraction is structurally minor and, being static, does not fatigue-cycle. The flat-plate expression overstates the force: a three-dimensional integration of the field gradient over the meshed blocks returns 2.69 kN, some 37% lower, because the assumed 0.55 T is not the mean normal field over the separation plane. Jensen’s inequality acts in the opposite direction and does not explain the overestimate. Extending the Maxwell-stress plane beyond the magnet footprint gives 2.680 kN, within 0.25% of the 2.687 kN volume-force calculation; this is model-to-model agreement, not experimental validation. The earlier finite-element load remains conservative.

Arrest and roller loads. At the 200 g arrest cap the 9.445 kg sled develops 18.5 kN axially, reacted by the ring-spring stop; the pitch couple during braking loads the guide rollers to roughly 1.48 kN per pair. This is the load path most affected by adopting the CAD-derived sled mass—it very nearly doubles—and it is the one place where the heavier sled makes the machine harder rather than merely slower. Bearing selection at 1.48 kN per pair is within the rating of a 440C/Si3N4 hybrid of this size, but the reuse duty is not addressed here: the sled is braked twelve times per campaign in vacuum, and no lubrication or contact-life assessment has been performed. The abort latch, engaged only for a commanded abort, carries the 13.4 kg carriage at the abort deceleration, 0.42 kN, through dual A-286 pins at a margin above eight.

Fatigue and tolerance. Operational cycling is benign: the magnet bond sees 0.12 MPa per shot against a 10 MPa allowable, far below any endurance concern over the few hundred shots of a service life. Positional accuracy is set by the winding-to-magnet gap, whose −13%/mm thrust sensitivity dictates a ±0.05 mm shim tolerance to hold thrust within ±0.65%; this is a standard precision-shim assembly, not a novel requirement.

IX. THERMAL ANALYSIS

Thermally the deployer is a pulsed, low-duty machine: each shot deposits heat in milliseconds, and the following minutesto-orbit reject it. The per-shot budget is 850 J in the stator copper (835 J over the shot, 15 J over the regenerative braking pulse), 935 J in the brake fin, 111 J in the converter, and 91 J in the supercapacitor equivalent series resistance. Over a full twelve-shot campaign the total is 24.3 kJ; deposited into the roughly 13.5 kJ/K thermal mass of the structure this is a 1.8 K bulk rise, so no shot ever sees a meaningfully preheated machine and the adiabatic per-shot rises quoted earlier (0.35 K coil, 7.1 K fin) are the design drivers rather than steady state. The brake fin is the hottest element. Its corrected 0.344 kg CAD mass gives a 7.1 K adiabatic rise per shot and an 85 K twelve-shot no-cooling bound. No transient conduction or radiation model establishes how much of that rise decays between shots, and the repository carries both 10–20 s and 1200 s cadence assumptions. Recovering a quarter of the sled’s energy is worth more thermally than electrically: it is the brake fin, not the bank, that the reduction relieves. The existing 0.32 m²
radiator figure follows from an assumed 130 W rejection case, not from the cadence model. A transient thermal network and a resolved campaign schedule are required before either the between-shot fin temperature or radiator sufficiency is established. The orbital environment sets the endpoints: a hot-case beta-angle attitude with full solar and albedo input, and a cold-case eclipse, bound the supercapacitor and converter baseplates, both of which are specified to survive −40 to +60◦C with survival heaters covering the cold case at a few watts. The N45SH grade is selected precisely so the magnets tolerate the hot case without irreversible loss.
X. POWER ELECTRONICS

The drive is a three-phase two-level voltage-source inverter of six SiC MOSFET half-bridges (1200 V devices on the 96 V rail, a 60% derating that accommodates switching overshoot), commutated by field-oriented control synchronized to the sled position encoder. Isolated gate drivers with desaturation detection and active Miller clamp switch at 20–40 kHz, low enough to keep switching loss within the converter’s 97 J/shot budget. The winding inductance that filters the resulting ripple is computed rather than assumed, which it previously was not. A sheet-current model is turns-invariant, so the turns count is fixed instead by requiring the inverter to synthesize the phase voltage the machine demands at rated speed out of the sagged 90.9 V bus: this gives 19.7 µH, a 373 A peak phase current— distinct from, and larger than, the 339 A drawn at the DC link—and 25.2 mΩ per phase at unity modulation index at exit. Peak-to-peak ripple is then 16% of peak at 20 kHz and 8% at 40 kHz, adding 3.7 J to an 835 J copper budget. The loss consequence is therefore negligible across the range, but only its upper end produces a current that can fairly be described as filtered. The two-dimensional energy method omits end turns, so the inductance is a lower bound and the ripple figures upper bounds. Protection comprises cycle-by-cycle current limiting

TABLE VII
PRINCIPAL FAILURE MODES AND MITIGATIONS
Failure | Effect | Mitigation
Sled jam | Manifest
stranded
Caged | escapement; | dual-cassette
limits a jam to half the manifest; controlled-disposal host
Latch fails Early
release

Latch loaded only on abort; inertia retains during accel; three-inhibit fire chain
Sensor fault Wrong velocity

Redundant seat switches, encoder, photogate cross-check; no-fire on disagreement
Capacitor
cell

Reduced
energy

32 series cells; one shorted cell drops rail 3%, within margin
Inverter device

Phase loss Segmented winding; dual gate drive; degraded-thrust continue
Magnet
debond

Field loss 84× bond margin at 200 g; taper-limited arrest
CubeSat
misalign

Feed jam /
tip-off

Seat switches + optical check; no-fire interlock
Brake fault Sled
overrun

Ring-spring hard stop backs eddy brake; motor regen trim
Controller
fault

Loss of shot Safe-state inhibits; watchdog; abort to 45% stroke

in the gate-drive logic, DC-bus overvoltage clamping to absorb regenerative transients, and desaturation shutdown on device fault. The 96 V bank is thirty-two series cells; passive balancing resistors equalize cell voltage over the long inter-shot interval, adequate because the duty cycle leaves ample balancing time, and a bleed network plus commanded crowbar passivate the bank at end of life. Electromagnetic interference from the switching edges is contained by keeping the highdi/dt loop area small, filtering the bank input, and enclosing the converter in a shielded housing; the firing transient is scheduled after primary separation so no adjacent live payload is exposed. Redundancy is applied where a single fault would strand the manifest: the winding is segmented so a shorted coil degrades thrust rather than ending the campaign, and the gate-drive and sensing chains are dual.

XI. RELIABILITY AND FAILURE MODES

Table VII summarizes the principal failure modes in an FMEA form, with the mitigation designed into the architecture. The design philosophy throughout is that the satellite is retained passively during ascent, that no single electrical fault strands the manifest, and that any credible mechanism fault degrades gracefully rather than releasing a satellite in an uncontrolled state.

XII. SPACE ENVIRONMENT, EMC, AND STANDARDS

The materials selection of Sec. III-F is driven by the low-Earth-orbit environment. Outgassing is controlled to ASTM E595 limits (TML < 1%, CVCM < 0.1%) for every polymer, with dry-film MoS2 and confined PFPE grease replacing wet lubrication that would cold-weld or migrate in vacuum [22]. Atomic-oxygen exposure is handled by hard-anodized aluminium and SiO2-overcoated multilayer insulation on ram surfaces. Thermal cycling and radiation are within the ratings of the selected sinter, cells, and SiC devices for a mission of this duration; permanent-magnet aging over a few-hundredshot life is negligible given the operating field sits well below the knee. Vibration and shock survivability are demonstrated by the 109 Hz first mode and the launch-load margins of Sec. VI.
Electromagnetic compatibility centres on the stray field of the Halbach sled. The verified back-face profile of 22.7 mT at 10 mm, 4.3 mT at 20 mm, and 0.4 mT at 50 mm sets a magnetic keep-out: stored satellites are parked outside the near field by the cassette geometry, and thin silicon-steel septa on the cassette inner walls attenuate the static field further. The self-shielding weak side is oriented outward by design, so a magnetometer-carrying customer payload sees a field comparable to a conventional reaction-wheel assembly at the same standoff; a keep-out radius is published in the interface control document, with a waiver process for magnetically sensitive payloads. The switching transient is contained as in Sec. X and fired only after separation, so induced currents in adjacent radios or instruments are avoided by timing as well as shielding.

XIII. MANUFACTURING, COST, AND SCALABILITY

The machine is deliberately conventional to build. The stator is an ironless copper winding wound on a machined PEEK former to a ±0.1 mm slot tolerance and vacuumimpregnated with E595-qualified epoxy; the sled magnets are individually plated N45SH blocks bonded into a titanium carrier in a magnetized-assembly fixture that reacts the interblock forces, then shimmed to the ±0.05 mm gap. Assembly proceeds stator-to-track, track-to-structure, cassette population last so the satellites are installed only after the mechanism is verified, mirroring the quad-pack integration practice of heritage deployers. Calibration is a ground exercise: each unit fires a mass simulator across an instrumented catch to map currenttovelocity before flight. Because the sled and track are reusable, maintenance between campaigns is inspection rather than refurbishment.
On cost, a parametric estimate rather than a business case, and one that corrects an earlier assumption in this work. The recurring hardware was previously described as dominated by the magnet set and the SiC drive. A bill of materials built against the mass model does not support that: the magnet set is roughly 5% of recurring hardware cost and the drive 13%, while avionics, the supercapacitor bank and the positionsensing chain together account for approximately half. The ordering is robust even though the prices are not—no line item priced here carries a vendor quotation, but doubling the magnet cost still leaves it below a tenth of the total. The practical consequence is that this machine is an avionics and energystorage cost problem rather than a magnetics one, which is the opposite of where the design effort has gone. The per-shot energy cost is the striking figure. At 2.85 kJ drawn per ejection the electrical energy is under one watt-hour, met by solar recharge between shots at zero consumable cost, against the propellant a transfer vehicle would expend for the same manoeuvre. A spring deployer has no energy cost but also no programmability; VOLLEY buys deterministic per-satellite velocity for less than a watt-hour a shot.
Scalability follows the governing equations. Larger Cube-Sats are already covered by the payload family of Table III, trading velocity for mass at fixed force; higher velocity comes from a longer track (v ∝

√
L) or higher current rating; more satellites come from deeper cassettes at a linear mass cost. The architecture extends to lunar or deep-space secondary deployment unchanged in principle, since it needs no atmosphere and no propellant, with only the thermal and radiation ratings revisited for the destination environment.

XIV. OPERATIONAL CONCEPT AND MATURATION

A mission proceeds through launch with the deployer dormant and the sled cam-locked; commissioning and health check once the host reaches orbit; bank charge from the host or internal battery; and a deployment campaign in which the sequencer computes each firing time from the host state, verifies the three-inhibit chain, fires, and confirms release by photogate before advancing the magazine. Contingencies branch to abort-and-restow within the first 45% of any stroke, or to safe the bank and hold. The campaign closes with bank passivation and, for a hosted stage, folding the accumulated recoil into the host’s controlled-disposal burn, following the zero-debris precedent of POEM-3 [14].
The maturation path is unusually testable on the ground. The present work is the analytical-model phase, TRL 2– 3, with the independent field verification of Sec. IV-B and the cross-validated astrodynamics of Sec. IV-C. A benchtop single-cassette track at reduced energy advances to TRL 4; a full 1.5 m track firing a mass simulator into the eddy brake, with the complete feed cycle, reaches TRL 5 and converts the velocity, dispersion, and tip-off claims into measured data within a university laboratory budget; vacuum and vibration qualification of the mechanism follows at TRL 6. The flight step is the captivecarry demonstration of Sec. VI-D, firing full cycles with a payload never released, reaching TRL 7 without any deployment approval, before an operational orbital deployment.

XV. LIMITATIONS

Six limits bound the claims. The atmosphere model is static, so absolute lifetimes carry severalfold uncertainty; an earlier version of this paper offered the invariance of the lifetime ratio as the defensible result in their place, and Sec. V-B records why that was wrong—the sweep supporting it could not have detected a change. The ratio is now quoted at a stated activity level and carries the same uncertainty as everything else derived from a static atmosphere. The thrust constant is winding-resolved in two dimensions; three-dimensional end effects of a few percent remain for finite-element closure. The brake law is first-order plate drag, acceptable at an orderof-magnitude authority margin. Conjunction figures, although refined at candidate minima, do not replace per-shot collision-avoidance products. Host budgets are parametric wherever stage properties are not public. Masses now derive from detailed CAD rather than the parametric solid model used earlier, and the two disagree: exact solid volumes give a 9.445 kg sled against the 4.86 kg the parametric model assumed. The CAD-derived value is adopted here and sets the headline velocity, but it is the as-drawn, unpocketed geometry—the structural analysis reports a 17-fold stress margin on the chassis plate, so a rib-stiffened redesign would recover mass, and none has been evaluated. The sensitivity, mechanical, thermal, power-electronics, and reliability analyses added here (Secs. VII–XIV) address the principal engineering questions only at analysis level. Several remain feasibility-significant: the commercial capacitor strings examined do not meet the ESR requirement, three-dimensional field closure remains open, and hardware validation has not begun.

XVI. CONCLUSION
A magazine-fed linear-motor deployer addresses, on numerically cross-checked model outputs, a deployment regime that current hardware leaves empty. The design ejects unmodified 3U CubeSats at 16.4 m/s within standard qualification loads, at 21.0% electricaltopayload efficiency net of regenerative recovery and 0.027 m/s dispersion, from a 76.5 kg system compatible with any restartable stage or hosted platform meeting a four-item interface. That authority converts into utility no spring provides and no transfer vehicle economically matches for this payload class: a 1.62-fold lifetime multiplier per shot at mean solar activity, and constellation spacing established in days rather than weeks. The velocity is 6.6 times the fastest published spring comparator and is set by a sled mass computed from detailed CAD solid volumes rather than estimated; recovering the 20.4 m/s of the earlier parametric design is a mass-reduction problem with a quantified target, not an open question. The concept asks one question of any launch provider, the mass and control authority of its stage, and offers in return a way to sell every rideshare customer their own orbit.

REFERENCES

[1] C. Lewis, “Failure of the ball-lock mechanism on the NanoRacks CubeSat deployer,” in Proc. 44th Aerospace Mechanisms Symp., 2018.
[2] JAXA, “JEM payload accommodation handbook, vol. 8: Small satellite deployment interface control document,” via UNOOSA KiboCUBE.
[3] NASA SSVI, “State-of-the-art of small spacecraft technology: Integration, launch, deployment, and orbital transport.”
[4] “Design and analysis of a new deployer for the in orbit release of multiple stacked CubeSats,” Remote Sensing, vol. 14, no. 17, 4205, 2022.
[5] B. N. Turman et al., “Coilgun launcher for nanosatellites,” Sandia National Laboratories, OSTI.
[6] R. J. Kaye et al., “Electromagnetic coilgun launcher for space applications,” Sandia National Laboratories, OSTI 125180.
[7] K. Halbach, “Design of permanent multipole magnets with oriented rare earth cobalt material,” Nucl. Instrum. Methods, vol. 169, pp. 1–10, 1980.
[8] R. F. Post and D. D. Ryutov, “The Inductrack: A simpler approach to magnetic levitation,” IEEE Trans. Appl. Supercond., vol. 10, no. 1, pp. 901–904, 2000.
[9] F. Faure et al., “Qualification of COTS supercapacitors for space applications,” ESA Space Passive Component Days, 2018.
[10] “Towards supercapacitors in space applications,” European Space Power Conf., 2017.
[11] “Eddy current damper modelling for space mechanisms,” Actuators; CDA InterCorp flight-heritage documentation.

[12] C. Foster et al., “Constellation phasing with differential drag on Planet Labs satellites,” J. Spacecraft and Rockets, vol. 55, no. 2, 2018.
[13] C. Foster, H. Hallam, and J. Mason, “Orbit determination and differential-drag control of Planet Labs CubeSat constellations,” arXiv:1509.03270, 2015.
[14] ISRO, “PSLV-C58/XPoSat mission: POEM-3 accomplishes zero orbital debris mission,” Mar. 2024.
[15] ISRO, “POEM-4 completes 1000 orbits in space,” 2025.
[16] NanoRacks, “NanoRacks CubeSat deployer interface definition document,” 2018.
[17] D. A. Vallado, Fundamentals of Astrodynamics and Applications, 4th ed. Microcosm Press, 2013.
[18] Skyroot Aerospace, “Orbit Adjustment Module full stage-level test,” public statement, Oct. 14, 2025.
[19] J. Foust, “Skyroot prepares for first orbital launch attempt,” SpaceNews, Jul. 7, 2026.
[20] Exolaunch, “CarboNIX” and “EXOpod Nova” product documentation; Exolaunch–Skyroot partnership announcement, Oct. 14, 2025.
[21] NASA, “General Environmental Verification Standard (GEVS),” GSFC-STD-7000A, 2013.
[22] ECSS, “Space engineering: Structural and mechanical / materials standards,” ECSS-E-ST-32 and ECSS-Q-ST-70 series.
[23] California Polytechnic State Univ., “CubeSat Design Specification,” Rev. 14, 2020.
[24] E. Kulu, “Nanosats Database,” nanosats.eu, counts as of Jan. 1, 2026.
[25] Novaspace, “Prospects for the Small Satellite Market,” 11th ed., 2026. Market forecast, not a measurement.
[26] Bellatrix Aerospace, “Bellatrix Aerospace and NSIL sign MoU to integrate Bellatrix’s OTV in NSIL’s launch missions,” Oct. 9, 2024.
[27] H. Feng, Y. Yang, and Y. Wu, “Design and reachable domain analysis of on-orbit electromagnetic launcher for CubeSats,” Int. J. Aerospace Eng., vol. 2025, art. 3000765, 2025.
[28] D. Xu, H. Yue, Y. Zhao, F. Yang, J. Wu, X. Pan, T. Tang, and Y. Zhang, “Improved A* algorithm for path planning based on CubeSats in-orbit electromagnetic transfer system,” Aerospace, vol. 11, no. 5, art. 394, 2024.
[29] Y. Zhao, Y. Zhang, Z. Zhao, C. Li, L. Zhang, X. Yang, H. Yue, et al., “Simulation analysis and experimental verification of the transport characteristics of a high-volume CubeSat storage device,” Aerospace, vol. 12, no. 6, art. 466, 2025.
[30] Y. Zhao, H. Yue, X. Mu, X. Yang, and F. Yang, “Design and analysis of a new deployer for the in-orbit release of multiple stacked CubeSats,” Remote Sensing, vol. 14, no. 17, art. 4205, 2022.
[31] M. Einat and Y. Orbach, “A multi-stage 130 m/s reluctance linear electromagnetic launcher,” Sci. Rep., vol. 13, 2023.

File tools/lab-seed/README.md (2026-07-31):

# VOLLEY, Phase II

The research track of the VOLLEY programme.

<!-- PROGRAMME-HEADER-START -->
| Repository | Role | You are here |
|---|---|---|
| [VOLLEY](https://github.com/aaaaaaaaaaaavm/VOLLEY) | Flagship, authoritative engineering record, portfolio | |
| [VOLLEY-paper](https://github.com/aaaaaaaaaaaavm/VOLLEY-paper) | IEEE companion, manuscript and reproducibility package *(generated)* | |
| [VOLLEY-thesis](https://github.com/aaaaaaaaaaaavm/VOLLEY-thesis) | Thesis companion, university submission *(generated)* | |
| **[VOLLEY-lab](https://github.com/aaaaaaaaaaaavm/VOLLEY-lab)** | Phase II, research, redesign, deliberately unstable | |
<!-- PROGRAMME-HEADER-END -->

> ## This repository makes no promises
>
> No frozen baseline. No stability requirement. Numbers here may be wrong, half-finished, or
> abandoned mid-thought. **Nothing in this repository should be cited.**
>
> The engineering record is the [flagship](https://github.com/aaaaaaaaaaaavm/VOLLEY). If
> anything here disagrees with it, the flagship is right.

## Why this exists

The [flagship](https://github.com/aaaaaaaaaaaavm/VOLLEY) is a Phase I deliverable and its
stability is a design requirement. This repository is the pressure valve that lets it stay
frozen.

A Phase II track kept *inside* the flagship is a soft boundary, one `git checkout` from
becoming an edit to the frozen baseline. This is a hard wall instead of a line on the floor.

**Redesign freely here. Do not touch the baseline there.**

## What belongs here

Anything that would make the design **better** rather than **correct**. The deferred list and
each item's entry criterion live in the flagship's
[`docs/PHASE_II.md`](https://github.com/aaaaaaaaaaaavm/VOLLEY/blob/main/docs/PHASE_II.md):

| | |
|---|---|
| PII-1 | Momentum-transfer release, recovers the full velocity shortfall for 1.6 % of shot energy |
| PII-2 | Rib-stiffened chassis, A4 leaves a 17x stress margin unspent |
| PII-3 | Two-layer stator (G3-D4), sits upstream of K<sub>t</sub> |
| PII-4 | Envelope repackaging (P9), currently 44 % over ESPA Grande |
| PII-5 | Variable-shape atmosphere, the root cause behind P16 |

More arrived on 2026-07-30, from reading the nearest published work and from the bank finding:

| | |
|---|---|
| PII-6 | **Reachable-domain analysis.** Feng et al. compute a 3-D envelope of the orbits one shot makes available. The flagship reports a scalar lifetime multiplier instead, which answers a smaller question. Their method is better and this is where adopting it belongs |
| PII-7 | **A bank that can source the shot.** P26 found the flagship's supercapacitor bank specified at an ESR no commercial cell achieves, and the shot does not close at a realistic value. Costed at four parallel strings in the flagship's PHASE_II.md |
| **PII-8** | **[VOLLEY as a free-flyer](https://github.com/aaaaaaaaaaaavm/VOLLEY-lab/blob/main/PII-8_free_flyer.md).** A long deployed track plus release at perigee reaches TLI and Mars-class C3 without exceeding CubeSat qualification. Three hard problems in front of it, named in the file |
| **PII-9** | **[The lunar case](https://github.com/aaaaaaaaaaaavm/VOLLEY-lab/blob/main/PII-9_lunar.md).** Where this technology actually belongs, and the mass driver it descends from. 1.33 MJ/kg to lunar orbit, so 15 kW launches a tonne a day |
| PII-10 | **Magazine indexing disturbance** (E24). Xu et al. treat the attitude disturbance from moving satellites inside a deployer as a cost worth optimising against. The flagship budgets recoil from the shot and nothing from the indexing between shots. The bookkeeping half is an error correction and belongs upstream; designing an indexing sequence that minimises it belongs here |

Also: anything from dossier §8's cross-industry list that turns into real work, and any idea
that does not yet have a home.

## What does not belong here

**Error corrections.** If something in the flagship is *wrong*, fix it in the flagship. The
distinction is the whole of the change-control rule in
[`BASELINE.md`](https://github.com/aaaaaaaaaaaavm/VOLLEY/blob/main/docs/BASELINE.md), and it is by
type, not by convenience. P17 is tedious and belongs upstream; the momentum-transfer release
is fascinating and belongs here.

## How work gets out

Only at a **baseline boundary**: the next opens after thesis submission, and only by meeting
the entry criterion written when the item was deferred. Not by seeming promising.

That rule exists for the same reason acceptance bands are declared before runs: a criterion
written afterwards is written by someone who already knows what they want the answer to be.

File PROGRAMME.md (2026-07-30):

# The EMOCD Engineering Programme

Four repositories, one programme. **This one is the flagship and the authoritative
engineering record.** If any other repository disagrees with this one, this one is right.

<!-- PROGRAMME-HEADER-START -->
| Repository | Role | You are here |
|---|---|---|
| **[EMOCD](https://github.com/aaaaaaaaaaaavm/EMOCD)** | Flagship, authoritative engineering record, portfolio | |
| [EMOCD-paper](https://github.com/aaaaaaaaaaaavm/EMOCD-paper) | IEEE companion, manuscript and reproducibility package *(generated)* | |
| [EMOCD-thesis](https://github.com/aaaaaaaaaaaavm/EMOCD-thesis) | Thesis companion, university submission *(generated)* | |
| [EMOCD-lab](https://github.com/aaaaaaaaaaaavm/EMOCD-lab) | Phase II, research, redesign, deliberately unstable | |
<!-- PROGRAMME-HEADER-END -->

---

## Why four

The programme has two competing goals, stated plainly in [`WHY.md`](WHY.md): finish
high-quality work now, and stay free to question everything later. Those goals fight each
other inside a single repository. So they are separated by structure rather than by
discipline, because my own account names spiralling into redesign as the failure
mode, and discipline is what fails first under that pressure.

| | Stability requirement | Who reads it |
|---|---|---|
| **EMOCD** | High, it is a Phase I deliverable | Aerospace companies, recruiters, reviewers |
| **EMOCD-paper** | Follows the flagship exactly | Researchers reproducing the work |
| **EMOCD-thesis** | Follows the flagship, plus university material | Examiners, viva panel |
| **EMOCD-lab** | **None. Instability is the point** | Me, and anyone curious about what comes next |

## Which are generated, and why that matters

**`EMOCD-paper` and `EMOCD-thesis` are generated by `tools/export_companion.py`. They are
never hand-edited.** Every file in them carries a header saying so.

This is not tidiness. The exit velocity `16.537 m/s` appears in nine places in the flagship
alone. Four hand-maintained repositories would make divergence a certainty, and this project
has already produced two forks of exactly that kind:

- The operating point forked between `analysis/motor_model.py` and `analysis/sizing.py`,
  now guarded by `_check_operating_point()`, which exits with a diagnostic if they drift.
- The paper figures forked from the analysis, now regenerated by `paper/make_figures.py`,
  which imports the analysis rather than reimplementing it.

Generation is the same answer applied a third time. If a companion is ever hand-edited, the
correct response is to delete and regenerate it, not to reconcile the two.

**If you found a mistake in a companion, fix it here.**

## Status of the four

| Repo | Populated | Files | Generated from |
|---|---|---|---|
| **EMOCD** | live, this one | | |
| [`EMOCD-paper`](https://github.com/aaaaaaaaaaaavm/EMOCD-paper) | **live** 2026-07-29 | 84 | flagship `c927df9` |
| [`EMOCD-thesis`](https://github.com/aaaaaaaaaaaavm/EMOCD-thesis) | **live** 2026-07-29 | 148 | flagship `c927df9` |
| [`EMOCD-lab`](https://github.com/aaaaaaaaaaaavm/EMOCD-lab) | **live** 2026-07-29 | 3 | seeded, then hand-written |

`EMOCD-paper` was checked before it was published, in the only way that means anything for a
reproducibility package: its `analysis/` was run from the clean pushed tree and returned
`v_exit = 16.537 m/s`, matching the flagship.

The **six milestone tags are also live** as of 2026-07-29, carrying their 2021-2026 design
periods, read [`HISTORY.md`](HISTORY.md) before citing any of those dates, since four of the
six are approximate and it says which.

**Still outstanding**, all of it needing ordinary GitHub access rather than anything this
repository can fix: the six **Releases** and the `v0.1.0` re-point
(`tools/publish_releases.sh`), repository descriptions and topics, and the programme board
(`tools/setup_project.sh`). Issues are disabled on this repository, that one is a settings
toggle, Settings to General to Features.

## Where redesign goes

`EMOCD-lab` is Phase II. Anything that would improve the design rather than correct it goes
there, the momentum-transfer release, the rib-stiffened chassis, the two-layer stator, the
envelope repackaging.

It has no baseline and makes no stability promise. That is deliberate: it is the pressure
valve that lets the flagship stay frozen. Items leave it only at baseline boundaries, against
criteria written when they were deferred, see [`docs/PHASE_II.md`](docs/PHASE_II.md).

## Reading order

**If you have sixty seconds:** [`SUMMARY.md`](SUMMARY.md).
**If you want to know whether to trust it:** [`PROVENANCE.md`](PROVENANCE.md), then
[`OPEN_PROBLEMS.md`](OPEN_PROBLEMS.md).
**If you want to know what it currently claims:** [`BASELINE.md`](BASELINE.md).
**If you want to know why any of it is the way it is:** [`WHY.md`](WHY.md), then
[`docs/adr/`](docs/adr/).

## Governance

[`docs/programme/ENGINEERING_PROGRAMME.md`](docs/programme/ENGINEERING_PROGRAMME.md) is the
governing document, committed verbatim.
[`docs/programme/ADOPTION.md`](docs/programme/ADOPTION.md) records every place practice
departs from it, with authorisation, including the decision to create these four
repositories in Phase I rather than defer them.

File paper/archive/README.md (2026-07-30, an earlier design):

# Archived paper builds

Superseded compiles of the EMOCD conference paper, kept for the record. **Do not cite
these.** The current paper is `../paper.tex` and `../VOLLEY_IEEE_Conference.pdf`.

## `EMOCD_submission_uncorrected.pdf`

An earlier build, predating the corrections of 2026-07-23. It still carries the four
values its own scripts did not reproduce (`OPEN_PROBLEMS.md` P1, P4, fixed per
`CHANGELOG.md` P2-01, P2-05):

| Quantity | This archived build | Corrected value |
|---|---|---|
| Peak current | 323 A | 392 A |
| Copper current density | 23 A/mm² at 140 kA/m | 21 A/mm² commanding 126 kA/m |
| Brake fin temperature rise | 37 K per shot | 3.0 K per shot (37 K is the 12-shot campaign bound) |
| Conjunction | 45.3 km minimum, 52 km median | reframed on the robust 8.1-day phase realignment |

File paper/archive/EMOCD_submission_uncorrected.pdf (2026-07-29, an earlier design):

# EMOCD: A Linear-Motor Electromagnetic Deployment System for Deterministic CubeSat Orbit Seeding from Small Launch Vehicles

Adityavardhan Mishra
Department of Mechanical Engineering, Symbiosis Institute of Technology Symbiosis International (Deemed University), Pune, India
PRN 23070125054

Abstract—Secondary payloads on rideshare missions inherit the orbit of the primary customer, and the spring deployers that release them impart 1–2 m/s, too little to alter that orbit in any useful way. This paper presents the design and analysis of EMOCD, a magazine-fed electromagnetic deployer that ejects unmodified CubeSats at a programmable velocity an order of magnitude above spring systems while remaining within standard qualification loads. An architecture trade selects an ironless double-sided Halbach-array linear synchronous motor driving a reusable permanent-magnet sled along a 1.5 m track, with twelve 3U satellites fed from two transverse cassettes, a contactless eddy-current arrest brake, and supercapacitor pulse power. A winding-resolved motor model, cross-checked against an independent magnetostatic computation, gives a thrust constant of 11.2 N per kA/m with ±1.3% ripple and an exit velocity of 20.4 m/s for a 3U payload at 16.3 g, drawing 2.63 kJ per shot at 32% electricaltopayload efficiency (70% total electrical-to-kinetic conversion, the sled’s share being dissipated in the arrest brake by design). Closed-loop simulation with realistic sensing yields a velocity dispersion of 0.027 m/s (3σ), equivalent to ±0.10 km of apogee placement. One maximum-velocity ejection multiplies a propulsion-less satellite’s orbital lifetime by 1.8, a ratio shown invariant across ballistic coefficient and a fivefold solar-activity density range, and differential ejection velocities of 2–10 m/s establish 30◦
constellation spacing in 1.4–6.9 days against 25 days for differential-drag phasing under identical assumptions. A parametric solid model closes the system at 72 kg dry and 120 kg loaded. Host integration is developed generically for any restartable upper stage or hosted platform, with ISRO’s POEM and Skyroot’s Vikram-1 kick stage analyzed as candidate first hosts.
Index Terms—CubeSat deployment, electromagnetic launch, Halbach array, linear synchronous motor, rideshare, constellation phasing, small launch vehicles.
I. INTRODUCTION
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

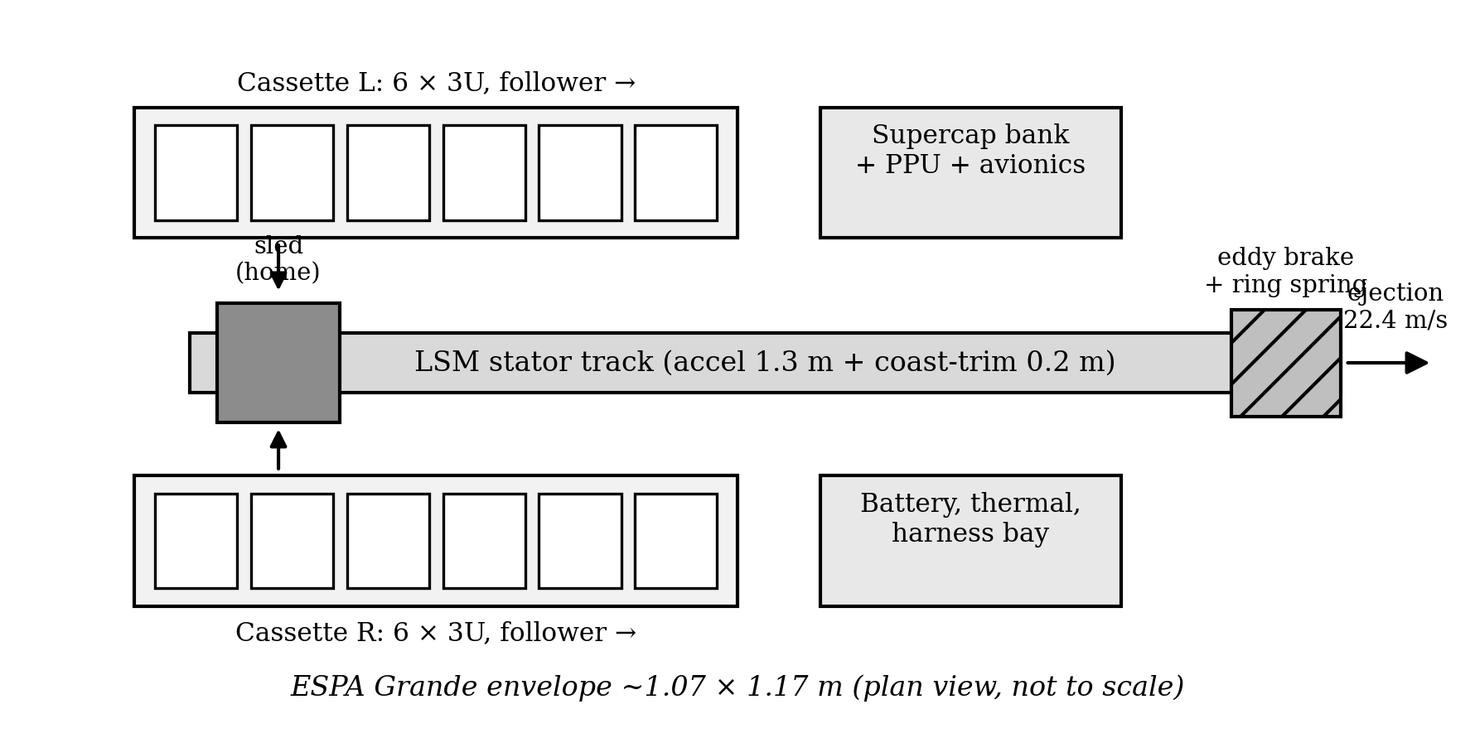
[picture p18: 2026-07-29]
paper/figures/D02_layout.png

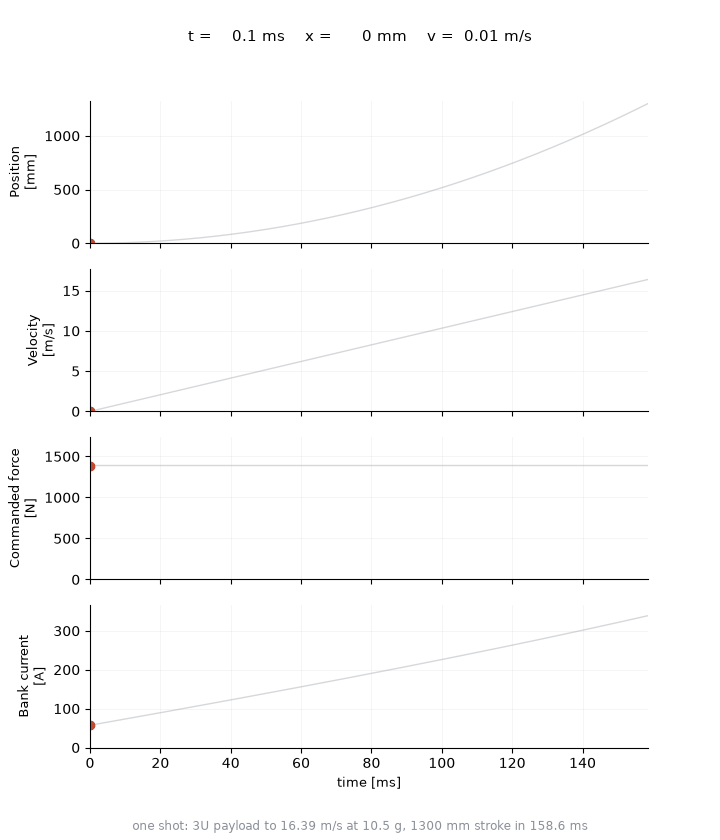
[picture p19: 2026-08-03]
paper/figures/shot.gif

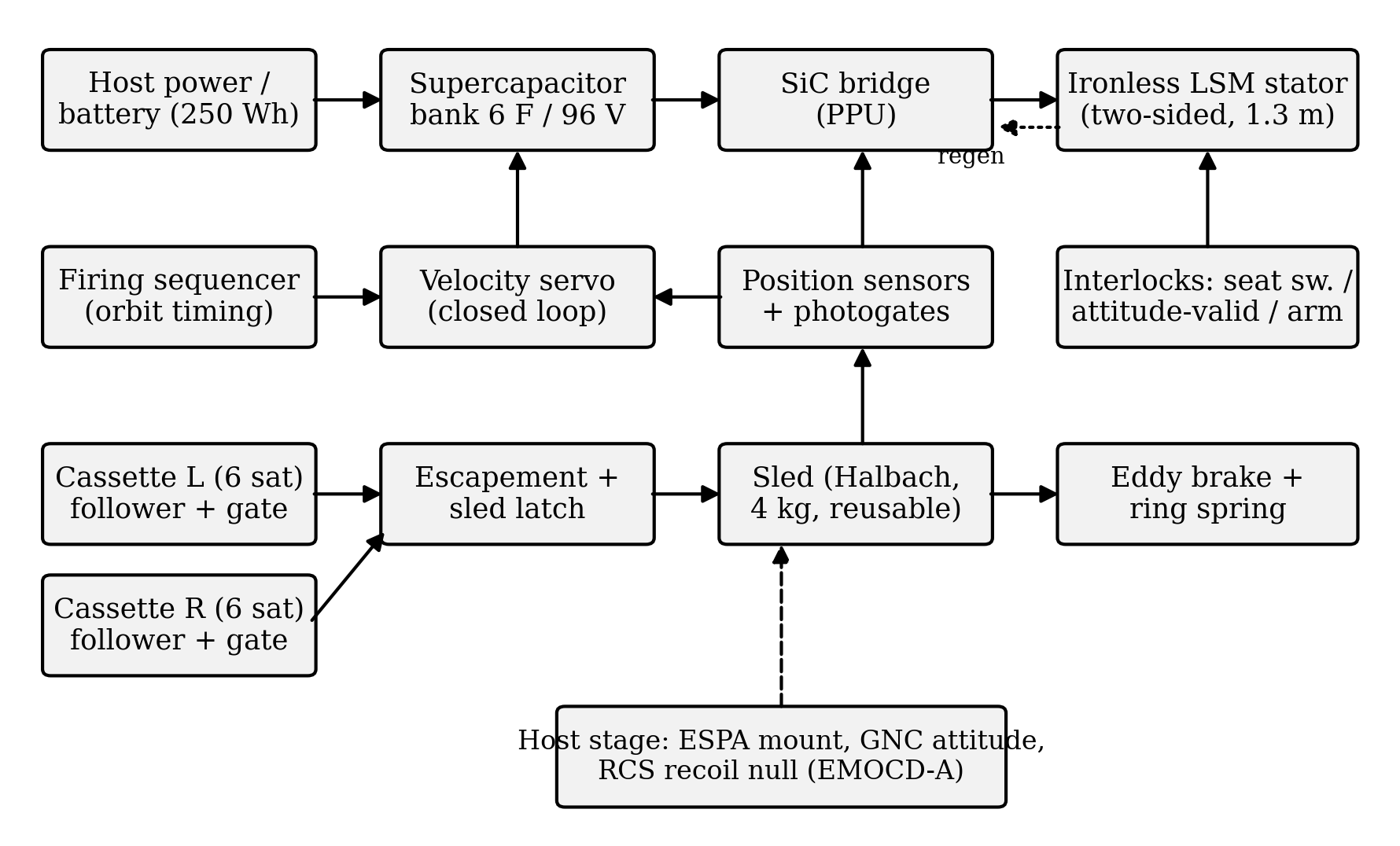
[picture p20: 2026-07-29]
paper/figures/D01_block.png

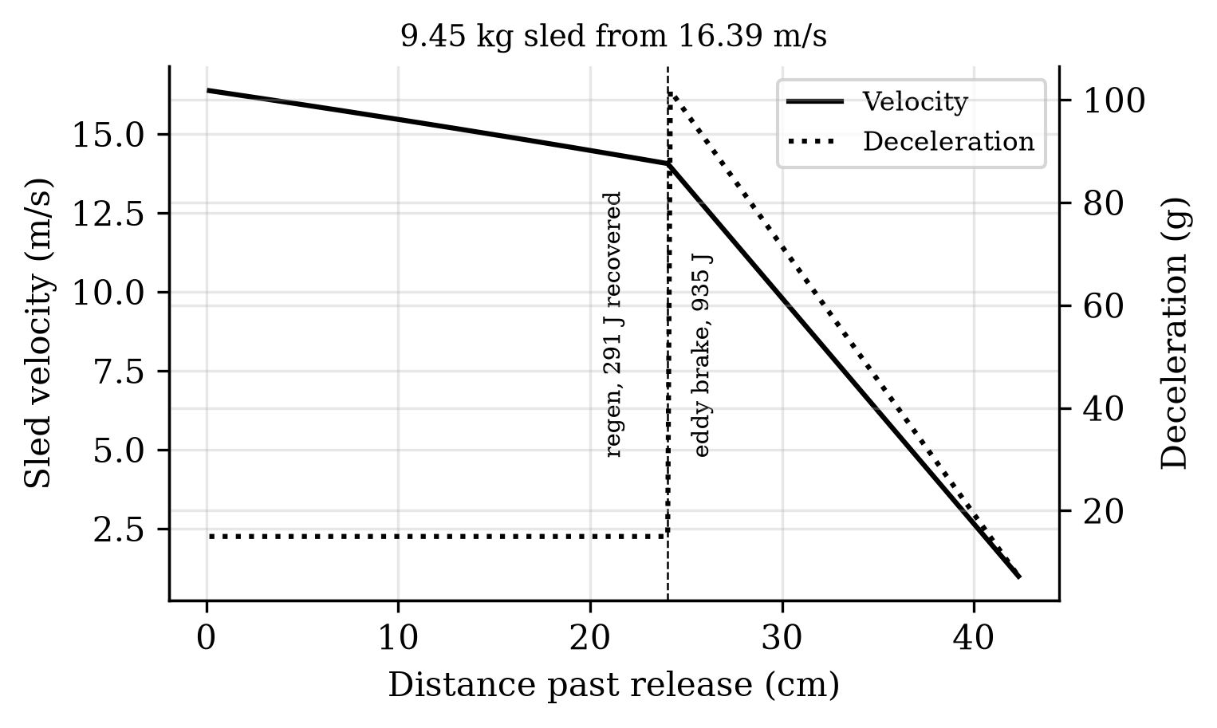
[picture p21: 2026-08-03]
paper/figures/F08_brake.png

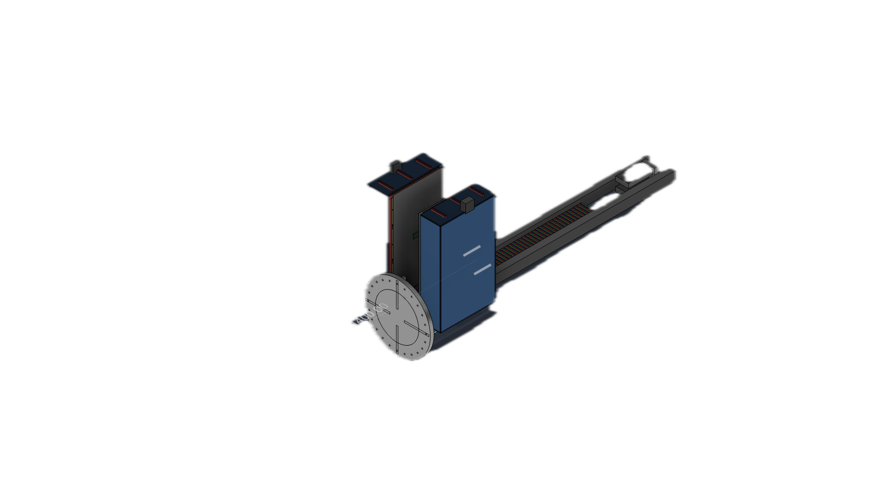
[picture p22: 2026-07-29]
cad/renders/seq4_braking.png

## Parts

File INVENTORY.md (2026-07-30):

# Inventory

Complete index of the work. Read alongside `PROVENANCE.md`.

**Baseline:** nothing in this list has been validated by hardware, FEA, or third-party
review. Every entry is a model output or a design decision, and several superseded
entries are kept only so the record of what changed stays legible.

---

## A. Calculations

| # | Item | Where it lives now |
|---|---|---|
| A1 | Recoil examples from earlier feasibility doc (ISS 420 t; 500 kg OTV) | superseded |
| A2 | Separation-speed equation check (FS = ½Mv² + ½M₁V²) | superseded |
| A3 | Δa from 1.5 m/s at 400 km | superseded |
| A4 | Hohmann 350 to 500 km; single-impulse ellipse correction | superseded |
| A5 | Constellation drift per 10 m/s; de-orbit Δv | `analysis/astro.py` |
| A6 | Coilgun single-stage efficiency literature check (1-2 %) | paper Sec. II |
| A7 | g-load vs barrel length | paper Sec. III-B |
| A8 | Energy budget & capacitor mass at 50-100 m/s | superseded |
| A9 | CMG momentum sizing vs line-of-action offset | superseded |
| A10 | Second-document checks (200 kg recoil, 30 m/s apogee, supercap, pulse power) | verification only |
| A11 | Tumble-rate plausibility to 780 °/s falsified | see E13 |
| A12 | Payload-limited velocity ceiling v=√(2aL) | paper Eq. 1 |
| A13 | Coilgun vs LSM energy-per-shot comparison | paper Table I |
| A14 | Magazine packing, feed forces, CoM shift, cadence | paper Sec. III-C |
| A15 | Stage-as-momentum-sink: Δv/shot, torque, RCS propellant, cant, slew | paper Sec. IX |
| A16 | Flywheel vs reaction wheel vs RCS (redundancy proof) | design decision D9 |
| A17 | Envelope/stroke limits; ironless vs iron stator mass | paper Sec. III-B |
| A18 | C1 orbital lifetime (Gauss orbit-averaged) | `analysis/astro.py` |
| A19 | C2 drift seeding vs differential drag | `analysis/astro.py` |
| A20 | C3 Halbach field + shot ODE + Monte Carlo | superseded by A28/A29 |
| A21 | C4 eddy-brake sizing | `legacy/c3_c4_em.py` |
| A22 | C5 conjunction screening (v1 bugged to v2 staggered) | `analysis/astro.py` |
| A23 | C6, C10 host attitude, tip-off, rollups, error map, payload family | `analysis/` |
| A24 | magpylib field verification (two sign errors caught by probing) | `analysis/verify_field.py` |
| A25 | Sled-arrest force mismatch, earlier regen claim falsified | design decision D8 |
| A26 | Abort commit point recomputed (~45 %) | paper Sec. III-D |
| A27 | Efficiency bookkeeping error found (40 % to 32 %; now 20 % at the measured sled mass) | paper Sec. V-A |
| A28 | Winding-resolved thrust constant Kt = 11.22 N per kA/m | `analysis/motor_model.py` |
| A29 | Closed-loop servo Monte Carlo (3σ = 0.027 m/s) | `analysis/motor_model.py` |
| A30 | Solid mass properties (76.9 kg dry, sled 9.445 kg measured) | `analysis/mass_properties.py`, parametric 4.86 kg superseded 2026-07-29 |
| A31 | Cowell RK4 cross-validation (99.4 %) | `analysis/astro.py` |
| A32 | Solar-activity UQ, x1.62 multiplier | `analysis/astro.py`, **invariance falsified by GMAT, see P16**; BC half is the same tautology |
| A33 | Refined conjunction at final velocity | `analysis/astro.py`, see P1 |
| A34 | Strategy-doc verification (recoil, propellant, capacitor, trim tables) | verification only |
| A35 | Mechanical/thermal/electrical sizing anchors | `analysis/sizing.py` |
| A36 | Retention-gate resize (margin 0.5 to two D6 pins, 1.2) | `analysis/sizing.py` |
| A37 | **Recurring hardware cost, parametric BOM**: all prices assumed, no quotations | `analysis/cost.py`, corrects the paper's claim that magnets dominate |

## B. Design decisions and when they changed

Reasoning is recorded in `docs/DECISION_LOG.md`.

| # | Decision |
|---|---|
| B1 | Core concept: EM launcher on a rideshare placing sats in own orbits |
| B2 | Original dual option: maglev rail *or* coilgun |
| B3 | Reluctance to induction coilgun |
| B4 | **Coilgun to linear synchronous motor** (mid-2025) |
| B5 | Ironless vs iron-core stator |
| B6 | Reusable sled vs armature on customer satellite |
| B7 | Dual transverse cassettes vs revolver / 2-DOF / tandem |
| B8 | Eddy brake + ring spring replaces regen-only arrest |
| B9 | No CMG/flywheel in attached mode |
| B10 | Fixed cant instead of gimballed barrel |
| B11 | Aft ESPA port, barrel parallel, fire forward |
| B12 | Fire-last ConOps |
| B13 | Retention gate separating preload from release path |
| B14 | Three-inhibit no-fire chain |
| B15 | Coast-and-trim release zone |
| B16 | Materials rules (non-conductive on field, non-magnetic near track, E595) |
| B17 | POEM as host and flight-demo path |
| B18 | EMOCD-A / EMOCD-F variant split |
| B19 | Scope narrowed to 3U baseline claim |
| B20 | Rated sheet current 130 to 140 kA/m |
| B21 | Paper reframed host-specific to host-agnostic |
| B22 | Value proposition to propulsion-less niche + drift seeding |
| B23 | Publish publicly |

## C. Diagrams and CAD

| # | Item | Status |
|---|---|---|
| C1 | System block diagram | `paper/figures/D01_block.png` |
| C2 | Plan-view layout | `paper/figures/D02_layout.png` |
| C3 | Figure set v1 (11 figures) | superseded, `legacy/make_figs.py` |
| C4 | Figure set v2 at final numbers | `paper/figures/` |
| C5 | Concept illustration | `legacy/concept.py` |
| C6 | **CAD assembly** | `cad/`, 9 Fusion 360 documents in 3 generations; Gen3 current, plus a monolithic `EMOCD_Gen3.step` |
| C7 | **FEMM / FEA field maps** | does not exist, run sheet only |
| C8 | CAD generation history and defect audit | `cad/CHANGELOG_CAD.md` |

## D. Documents

| # | Item | Status |
|---|---|---|
| D1 | Verification report, feasibility PDF | not in repo |
| D2 | Verification report, consolidated docx | not in repo |
| D3 | Verification of strategy document | not in repo |
| D4 | Launch-ecosystem research report | not in repo |
| D5 | Computation results C1, C10 | `docs/`, **superseded**, old operating point |
| D6 | PBL-2 skeleton (19 pp, Annexure format) | not in repo |
| D7 | Figure pack | `paper/figures/` |
| D8 | FEMM run sheet | `analysis/femm/FEMM_RUN_SHEET.md` (current); `docs/FEMM_Run_Sheet.md` superseded; band in `validation/A1_field_femm.md` |
| D9 | IEEE showcase paper (5 pp, text-only) | superseded |
| D10 | IEEE conference paper (10 pp) | `paper/` |
| D11 | LaTeX source | `paper/paper.tex` |
| D12 | Reproducibility package | this repo |
| D13 | Analysis scripts | `analysis/` + `legacy/` |
| D14 | LinkedIn announcement post | not in repo |
| D15 | **Qualification and environmental test plan** | `docs/QUALIFICATION_PLAN.md`, specified, none run |
| D16 | **Benchtop test protocol** (4 sub-scale experiments, bands declared) | `docs/BENCHTOP_TESTS.md`, specified, none run |
| D17 | **Project history and milestone tags** | `HISTORY.md`, records that the git history below 2026-07-23 was reconstructed |

## E. Open problems

Full detail in `OPEN_PROBLEMS.md`. Summary: P1, P4 are errors in the published paper
(conjunction minimum, peak current, stray far-field, fin temperature), corrected in
`paper.tex`, though P11 asks whether those corrections reached the submitted build.
P5, P10 come out of the CAD build, and P12 records two places where the paper's prose
contradicts it, including an ESPA-Grande envelope claim the CAD does not support. E1, E18 are unsolved engineering, of which the
load-bearing ones are 3-D field closure, the absence of FEA and hardware, and the
patent position now that disclosure has happened.

## F. External sources

30 sources cited across the work; 21 were fetched and read directly ("verified"), the
remainder cited without retrieval and **should be re-checked before publication**. Full
list with verification status is in the paper bibliography and `PROVENANCE.md`. Three
references (eddy-damper heritage, Yudintsev, vibro-impact deployment) remain explicitly
unverified, see `OPEN_PROBLEMS.md` E16.

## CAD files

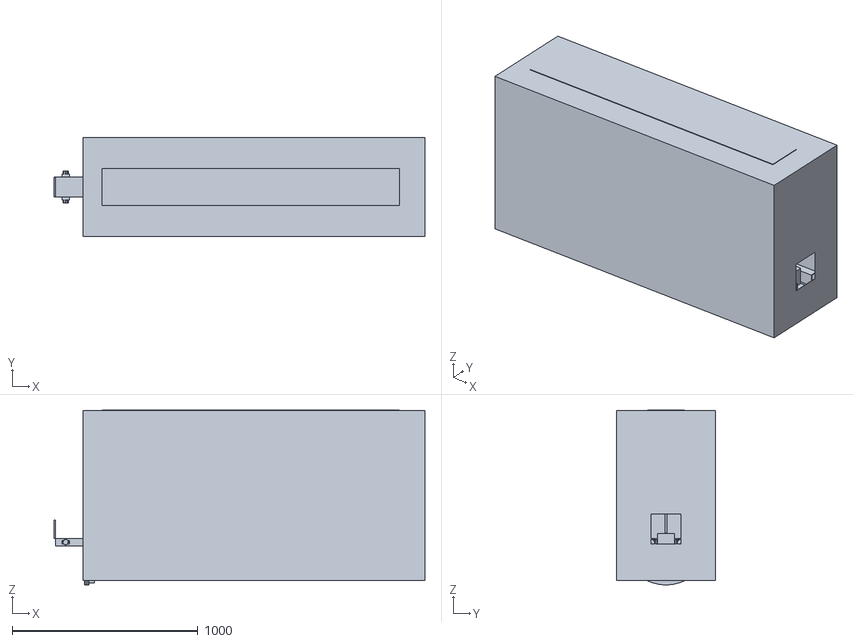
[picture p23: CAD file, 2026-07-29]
cad/stl/EMOCD_Assembly_Gen3.stl
1995.0 x 530.0 x 940.0

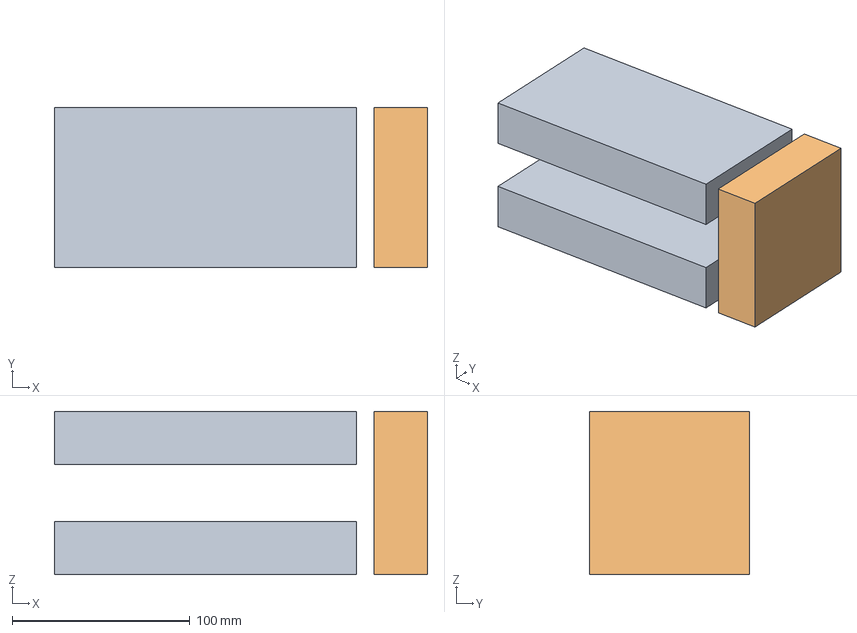
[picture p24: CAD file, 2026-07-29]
cad/step/gen3/EMOCD_Brake_Gen3.step
210.0 x 90.0 x 92.0 mm

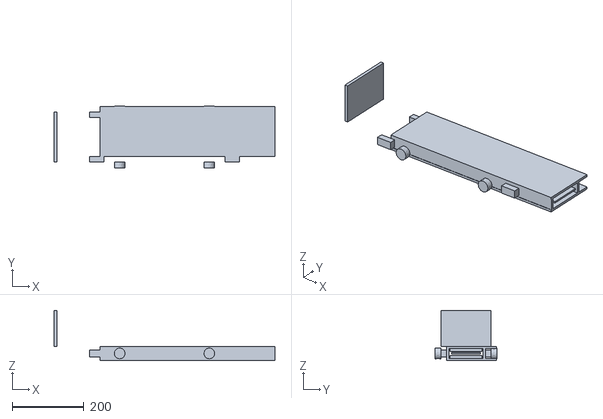
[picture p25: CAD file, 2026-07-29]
cad/stl/EMOCD_Sled_Gen3.stl
616.0 x 172.0 x 140.0

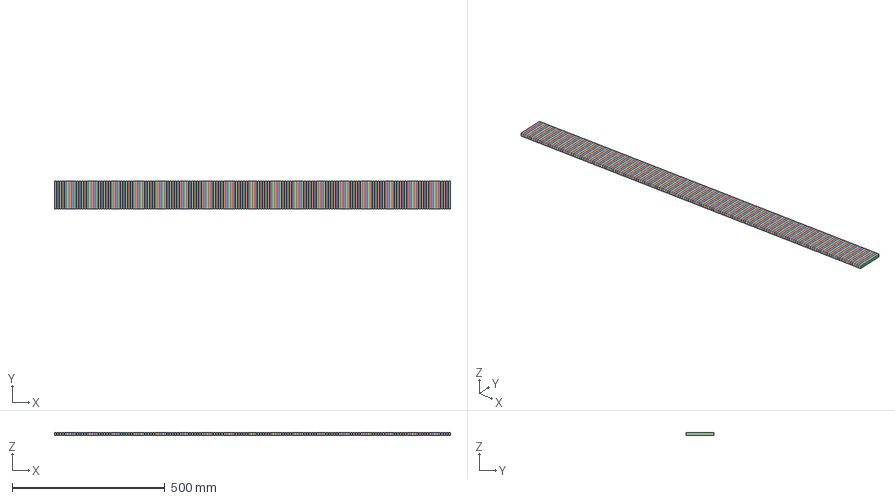
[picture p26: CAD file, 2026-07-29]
cad/step/gen3/EMOCD_Stator_Gen3.step
1295.0 x 90.0 x 10.0 mm

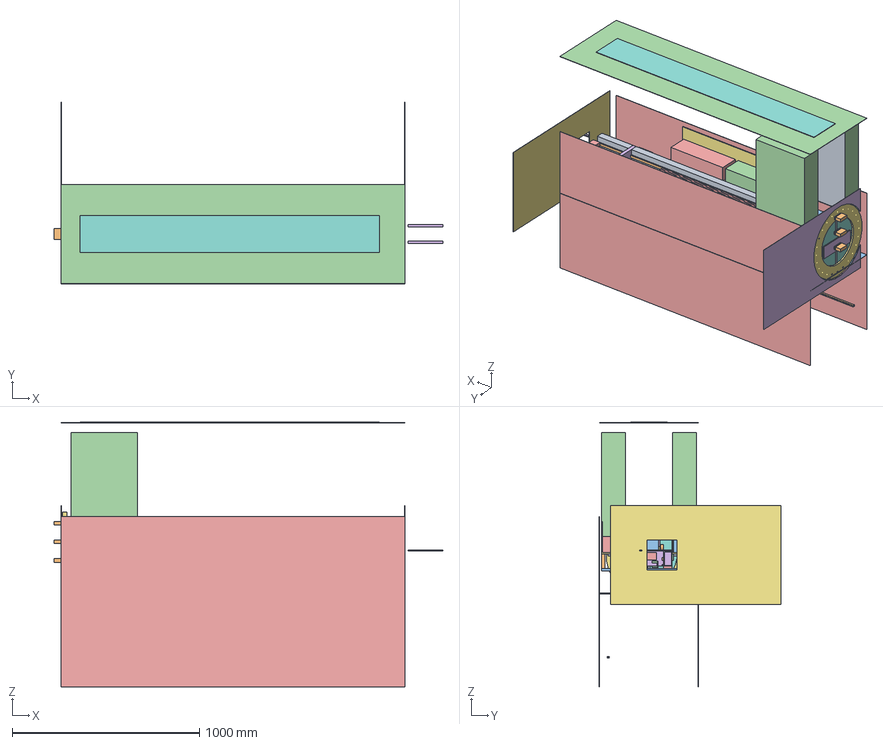
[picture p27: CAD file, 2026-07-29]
cad/step/gen3/EMOCD_Gen3.step
2080.0 x 972.0 x 1415.0 mm
01_Track
02_Stator
03_Sled
05_Payload
04_Cassette_P
04_Cassette_S
06_Brake
07_Avionics
08_Interface
09_Enclosure

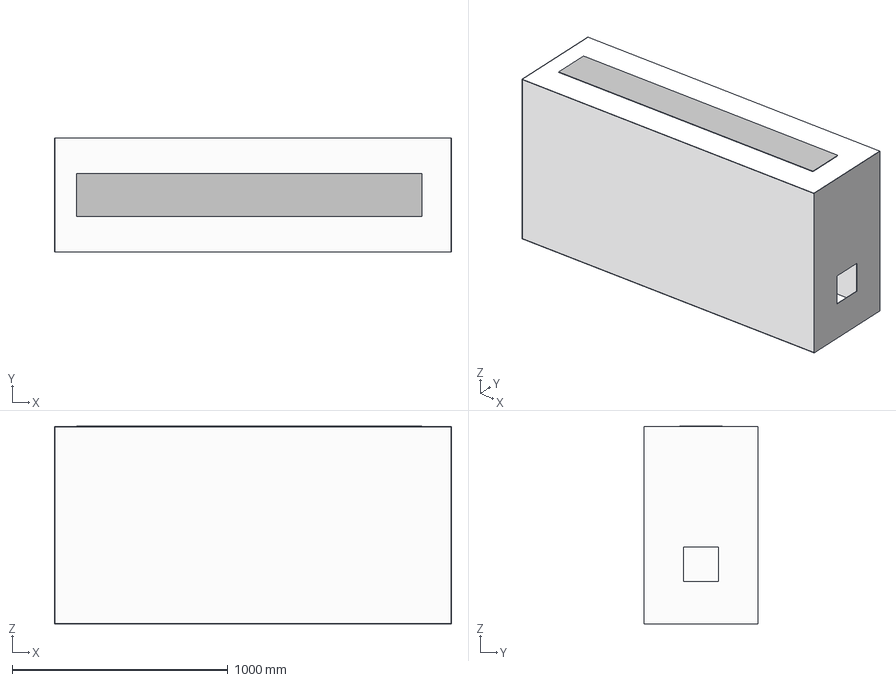
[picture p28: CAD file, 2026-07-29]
cad/step/gen3/EMOCD_Enclosure_Gen3.step
1839.0 x 530.0 x 917.0 mm

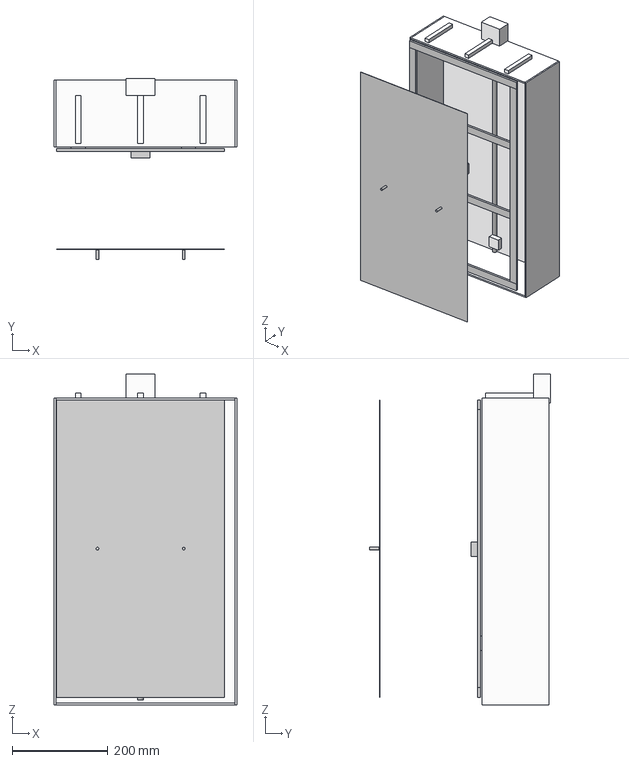
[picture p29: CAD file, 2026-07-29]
cad/step/gen3/EMOCD_Magazine_Cassette_Gen3.step
380.5 x 378.0 x 690.0 mm

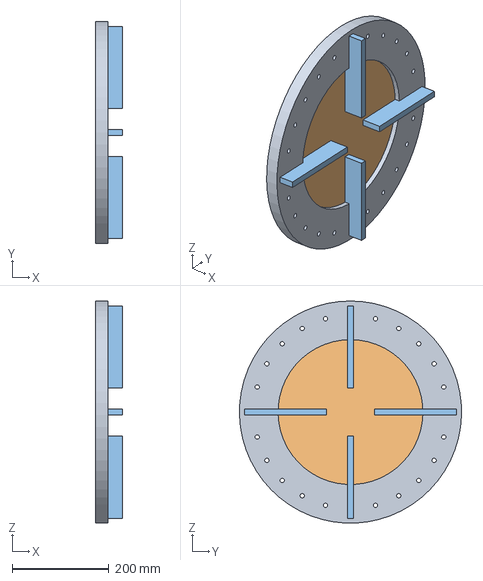
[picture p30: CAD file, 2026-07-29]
cad/step/gen3/EMOCD_Interface_ESPA_Gen3.step
55.0 x 459.8 x 459.7 mm

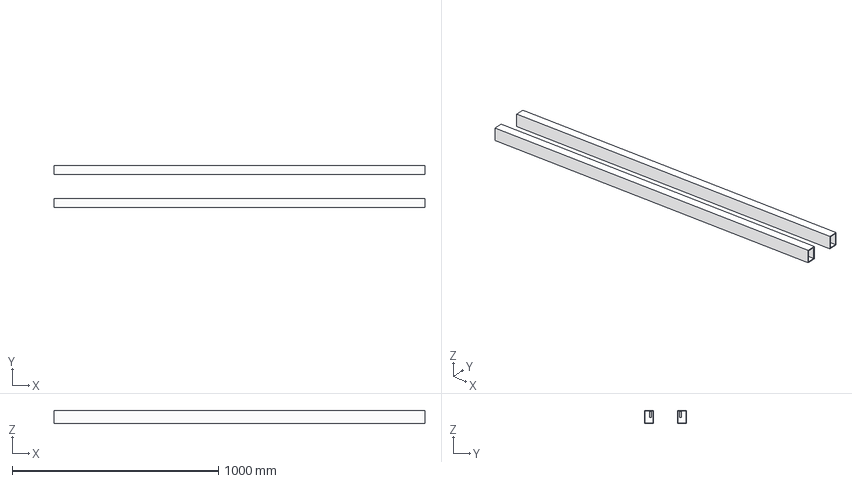
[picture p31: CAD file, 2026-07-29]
cad/step/gen3/EMOCD_Track_Gen3.step
1800.0 x 205.0 x 65.0 mm

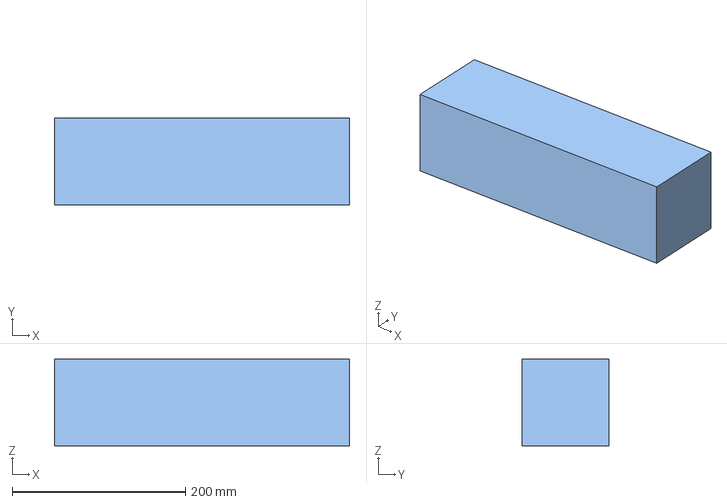
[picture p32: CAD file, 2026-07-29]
cad/step/gen3/EMOCD_Payload_3U_Gen3.step
340.5 x 100.0 x 100.0 mm

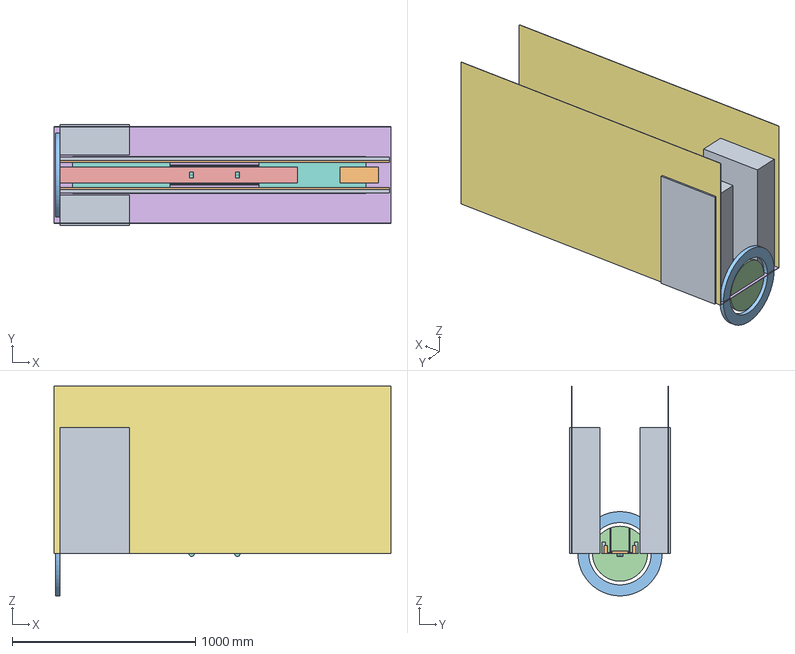
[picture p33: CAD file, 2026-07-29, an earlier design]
cad/step/gen1/EMOCD_Assembly_Gen1.step
1839.0 x 552.0 x 1143.6 mm

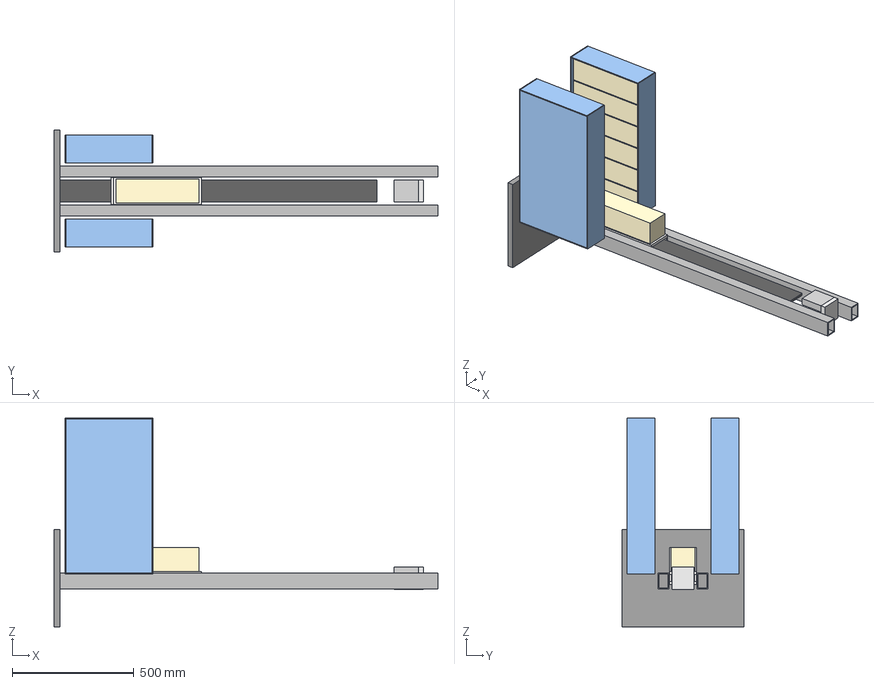
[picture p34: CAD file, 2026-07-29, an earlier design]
cad/step/gen1/EMOCD_Deployer_Assembly_Gen1.step
1575.0 x 500.0 x 856.0 mm
01_Track
02_Stator
03_Sled
04_Cassettes
05_Payload
06_Brake
07_Interface
08_Annotation

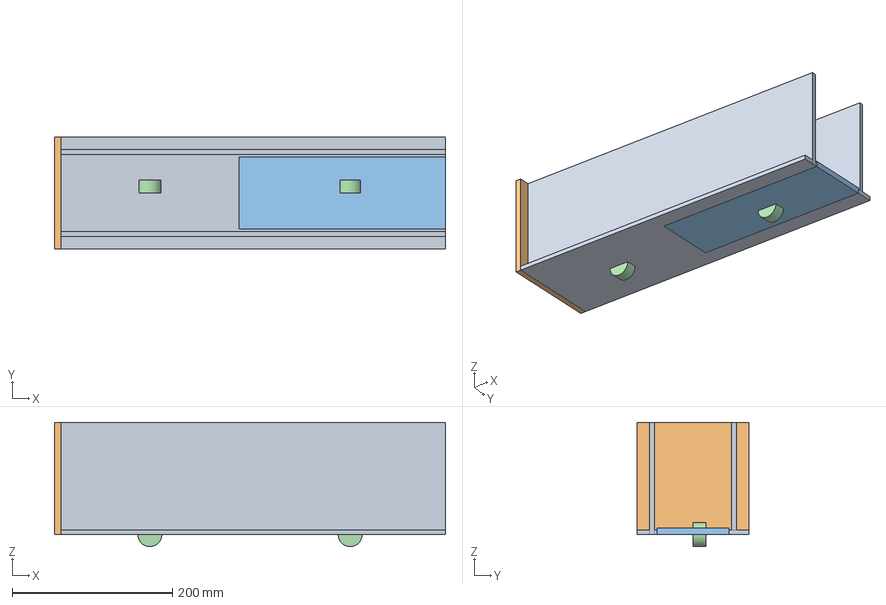
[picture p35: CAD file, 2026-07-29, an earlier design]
cad/step/gen1/EMOCD_Sled_Gen1b.step
488.0 x 140.0 x 155.0 mm

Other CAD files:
cad/step/gen3/EMOCD_Assembly_Gen3.step
analysis/femm/emocd_cross_section.dxf
cad/step/gen3/EMOCD_Sled_Gen3.step
cad/step/gen2/EMOCD_Assembly_Gen2.step
cad/step/gen2/EMOCD_Payload_3U_Gen2.step
cad/step/gen1/EMOCD_Brake_Gen1.step
cad/step/gen1/EMOCD_Enclosure_Gen1.step
cad/step/gen1/EMOCD_Interface_ESPA_Gen1.step
cad/step/gen1/EMOCD_Magazine_Cassette_Gen1.step
cad/step/gen1/EMOCD_Payload_3U_Gen1.step
cad/step/gen1/EMOCD_Sled_Gen1.step
cad/step/gen1/EMOCD_Stator_Gen1.step
cad/step/gen1/EMOCD_Track_Gen1.step
cad/step/gen2/EMOCD_Brake_Gen2.step
cad/step/gen2/EMOCD_Enclosure_Gen2.step
cad/step/gen2/EMOCD_Interface_ESPA_Gen2.step
cad/step/gen2/EMOCD_Magazine_Cassette_Gen2.step
cad/step/gen2/EMOCD_Sled_Gen2.step
cad/step/gen2/EMOCD_Stator_Gen2.step
cad/step/gen2/EMOCD_Track_Gen2.step

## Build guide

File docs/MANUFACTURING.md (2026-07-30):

# Manufacturability

The Engineering Programme Dossier names manufacturability three times, in the Phase I focus
list, in the philosophy (*"manufacturability over elegance"*), and in the validation chain.
Until 2026-07-29 this repository contained none. This document opens it.

**Status: analysis only.** Nothing has been quoted, no vendor has been approached, and no part
has been made. Every price and process tolerance below is an **assumption**, marked as such
under E16, exactly like `analysis/cost.py`.

---

## 1. The airgap tolerance stack: the finding

`sizing.py` declares a single `gap_shim_tolerance = 0.05 mm` against a thrust sensitivity of
**13.1 %/mm**, and reports a resulting spread of ±0.65 %. **That figure counts only the shim.
It does not count the parts.**

Three separate budgets were being conflated. Separated:

| # | Budget | Value | Status |
|---|---|---|---|
| 1 | Physical clearance per side | **1.000 mm** | `parameters.json` `sled.airgap_per_side` |
| 2 | A4 deflection band per plate | 0.025 mm | measured 0.0194, **78 % used** |
| 3 | Shim **setting** spec | ±0.050 mm | to ±0.66 % thrust |
| 4 | **Build stack** | **never computed** | below |

### The build stack

| Contributor | Assumed (mm) | Note |
|---|---|---|
| Track straightness over 1.8 m | 0.060 | **Dominant.** A 1.8 m extruded/machined Al assembly |
| Ti plate flatness over 488 mm | 0.050 | Post-machining, pre-shim |
| Roller / rail radial clearance | 0.040 | Bearing fit plus rail form |
| Magnet block thickness tolerance | 0.030 | Sintered NdFeB, ground faces |
| Chassis web height tolerance | 0.030 | |
| Bond line thickness variation | 0.020 | Adhesive under 12 blocks |
| Shim setting | 0.020 | The only term currently counted |
| **RSS** | **0.101** | to **1.33 % thrust** |

Combined with A4's deflection bias (0.0194 mm, always closing) the total gap error is
**0.121 mm, 2.4x the ±0.65 % currently claimed, giving ±1.58 % thrust spread.**

### What this does and does not mean

**It is not a contact risk.** 0.121 mm against 1.000 mm of clearance is 12 %; nothing touches.

**It is a claims problem.** ±1.58 % thrust spread propagates into the open-loop velocity
spread, which the paper states as ±2.1 % RSS from manufacturing terms. That figure was built
from magnet grade, gap, resistance and ESR, **with the gap term taken as the ±0.05 mm shim
rather than the real stack.** The closed-loop servo collapses delivered dispersion regardless
(ADR-014), so the headline 0.027 m/s survives. But the open-loop number is optimistic and
should be restated once these contributors are replaced with real ones.

**The individual values above are assumed.** The useful output is the ranking: **track
straightness and plate flatness dominate**, and no amount of shim precision fixes either.
Tightening the shim spec is the intuitive move and it is nearly worthless.

> **Not propagated.** Per `BASELINE.md` change control this is a discrepancy, not yet a
> correction, the contributors are assumptions, and replacing a real number with an assumed
> one is not an improvement. Closure needs a real tolerance study against quoted process
> capability. **Do not edit `sizing.py` on the strength of this section.**

## 2. Halbach assembly: the hazardous operation

`analysis/cost.py` puts the magnet set at only ~5 % of recurring cost. **It is far more than
5 % of the risk.**

Each array is 12 blocks of N45SH in alternating orientation, and the two opposed arrays attract
across the gap with **2.69 kN** (P17's corrected 3-D figure; the flat-plate formula says 3.67).
That is roughly 274 kgf trying to close a 12 mm gap, acting on brittle sintered material with
essentially no tensile strength.

Process implications, none of which are in the CAD:

- **Assembly fixture must be non-magnetic and must control the gap throughout closure**, not
  only at the end. There is no intermediate state where the halves are "nearly together" and
  safe.
- **A controlled-approach mechanism is required**, screw-driven or similar. Free approach ends
  in an impact between two brittle arrays.
- **Keep-out during assembly.** 2.69 kN closing on a hand is a serious injury.
- **Magnetisation order.** Magnetise-then-assemble is standard for Halbach arrays but makes
  every handling step hazardous; assemble-then-magnetise needs equipment most shops lack.
  **Not yet decided, and it changes the fixture completely.**
- **Bond cure under load**: the bond line is a stack contributor (§1) and cures while the
  attraction is trying to squeeze it.

**This is the single largest manufacturability unknown in the project**, and it is not
represented in cost, schedule, or the qualification plan beyond T-3's magnet-integrity check.

## 3. Make versus buy

Driven by `analysis/cost.py`, whose sensitivity table is the relevant output:

| Item | Share | Recommendation |
|---|---|---|
| Avionics, sequencer, IMU | 23.7 % | **Buy.** Nothing here is VOLLEY-specific |
| Supercapacitor bank | 17.8 % | **Buy** cells, make the pack, cell selection is commodity, the pack is not |
| SiC bridge + gate drive | 13.3 % | **Buy** the modules, make the busbar |
| Halbach arrays | ~5 % | **Buy magnetised blocks, assemble in-house**: see §2 |
| Ti chassis, track longerons | ~11 % | **Make** (subcontract machining). This is where DFM effort pays |
| Bearings, rails | 5.2 % | **Buy.** Vacuum-rated hybrid ceramics are catalogue items |

**The strategic point:** the project's cost and risk both concentrate in electronics and
assembly process, not in the electromagnetics the design effort has gone into.

## 4. DFM review of the Gen3 parts

| Part | Observation | Action |
|---|---|---|
| Chassis plate 488x140x6 | Drawn **solid**. A4 gives a 17x stress margin, so this is not a structural part, it is a stiffness part carrying dead mass | Pocketing is PII-2. Do not thin uniformly: deflection goes as 1/t³ |
| Track longerons, 1.8 m | Straightness dominates the tolerance stack (§1) | Specify straightness explicitly. It is currently unspecified anywhere |
| Halbach blocks | 12 per array, alternating orientation | Orientation-proof fixturing. A reversed block is invisible on inspection and destroys K<sub>t</sub> |
| Roller channels, guide flanges | **G3-D2: not modelled at all.** The rollers have nothing to run in | Blocking for any real build |
| Halbach array position | **G3-D5: not re-centred** after the chassis grew 360 to 488 mm | Array-to-winding position is what K<sub>t</sub> depends on. **Blocking, and it may invalidate K<sub>t</sub> independently of A1** |

## 5. Process route

```
Buy magnetised N45SH blocks  ──┐
Machine Ti chassis + webs  ────┼──> Bond arrays in controlled-approach fixture ──┐
Machine Al track longerons ────┘         (§2 — hazardous operation)              │
                                                                                 v
Wind stator on formers ──> pot ──> verify per-phase resistance ──> Integrate ──> Shim gap
                                                                                 │
                        Inspect: gap map, K_t on a load cell (B-2) <─────────────┘
```

**Inspection points that do not currently exist:** a gap map along the full 1.3 m stroke rather
than a single measurement, and a K<sub>t</sub> check on the built article. Both are in
`docs/BENCHTOP_TESTS.md` as B-1 and B-2 at sub-scale.

## 6. What would close this

1. **Real tolerance data.** Quote the seven contributors in §1 against actual process
   capability. Until then §1 is structure, not a number.
2. **A decision on magnetisation order** (§2). It changes the fixture, the hazard case and the
   schedule.
3. **G3-D2 and G3-D5** (§4). Both are blocking for a build and G3-D5 may move K<sub>t</sub>.
4. **One quotation**: any line item. `cost.py` currently has zero real prices, and a single
   quote would tell us whether the model is out by 20 % or by 200 %.

## Where this sits in the validation chain

Dossier §7: Concept to Analysis to **Simulation** to Prototype to Experiment to Repeatability to **Manufacturability** to Flight Qualification.

The project sits at Simulation. This document is the **first entry on the manufacturability
rung**, and it is analysis about manufacturing rather than manufacturing evidence. The rung is
opened, not climbed.

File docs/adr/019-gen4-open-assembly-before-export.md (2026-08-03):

# ADR-019: Keep the Gen4 open assembly separate from the frozen Phase I baseline

**Status:** Accepted · **Date:** 2026-08-03 · **Phase:** Gen4 transition

## Context

The committed Phase I model accelerates through a uniform 1.30 m active stator and
releases at 1500 mm. The reviewed `EMOCD_Gen4_Open v7` assembly instead uses the
488 mm sled at s = 300 mm stowed and s = 1200 mm release. Its 340 mm Halbach array is
fully over the stator for 751.5 mm of that 900 mm stroke. The final 148.5 mm is under
partial overlap; 191.5 mm of the array remains over the stator at release.

The new station keeps release 22 mm ahead of brake-fin entry and gives the fin 330 mm
of travel through the brake. It is a geometry decision, not a performance result.
Replacing the Phase I headline with a shortened-stroke constant-thrust calculation
would only make a new number look derived.

## Decision

Treat `EMOCD_Gen4_Open v7` as a provisional, open public assembly. Keep the enclosure
as a separate envelope-check configuration. Do not export Gen4 STEP, STL, or renders,
and do not quote a Gen4 operating point, until a finite-stator position-dependent
motor calculation has been run and its affected evidence has been classified.

## Alternatives

- **Keep the 1500 mm release station.** Rejected: the brake fin is already inside the
  brake envelope at release.
- **Extend the track and enclosure to retain the 1.30 m stroke.** Rejected for this
  revision: it enlarges the existing packaging problem and turns a CAD correction into
  a host-envelope decision.
- **Use a 900 mm constant-thrust calculation.** Rejected: the finite stator edge is
  encountered before release, so constant thrust is not the stated geometry.

## Consequences

The Phase I baseline remains visible and reproducible. The Gen4 configuration has no
public exit velocity, energy, efficiency, thermal, orbit, or regeneration claim yet.
P32 records the operating-point mismatch, and E27 records the missing finite-stator
force profile. P28 remains open because the Gen4 arrangement does not lay out the
Phase I regeneration section.

The choice retains a shorter track and an open explanatory assembly, but it delays CAD
export until the new geometry has a numerical basis.

## Validation

Implement a position-dependent field and force calculation over the finite stator,
with the Gen4 body bounds and stations as declared inputs. Record the implementation,
tool version, input hash, numerical settings, output hash, and comparison with the
existing infinite-period result where their domains overlap. Then identify every
validation and document that depended on the Phase I operating point before changing
any public number.

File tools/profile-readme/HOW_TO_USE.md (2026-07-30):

# Publishing the profile README

GitHub shows the README of a repository **named exactly after the account** at the top of the
profile page. It is the first thing a visitor sees after clicking through from a repository.

## One-time setup

1. Create a new **public** repository named exactly `aaaaaaaaaaaavm`.
   GitHub confirms when you have found the special repository name. If it does not, the
   name is wrong.
2. Copy `README.md` from this directory into it and push.

```bash
gh repo create aaaaaaaaaaaavm --public --description "Profile"
git clone https://github.com/aaaaaaaaaaaavm/aaaaaaaaaaaavm.git
cp <this-dir>/README.md aaaaaaaaaaaavm/
cd aaaaaaaaaaaavm && git add README.md
git commit -m "Profile" && git push
```

## Then pin the repositories

Profile, then **Customize your pins**, and select `VOLLEY`, `VOLLEY-paper`, `VOLLEY-thesis`, `VOLLEY-lab`.
Pinning is separate from the README and has to be done in the web UI. Without it the four
repositories sit below everything else on the account.

## Why this file lives here

It is kept in the flagship rather than in the profile repo so it stays with the rest of the
programme's tooling, next to `bootstrap_repos.sh` and `publish_releases.sh`. **This directory is
the source; the profile repo is a copy.** Edit here, then re-copy, the same
generated-not-maintained rule the companion repositories follow, for the same reason.

## Constraints it is written under

- **No hardware claim.** The repository's front page states that nothing has been built, fired or
  measured, and the profile has to agree with it. This changes the day `B-1` produces a number.
- **No skill-percentage bars, trophy widgets or streak counters.**
- **The paper is described as a manuscript**, because it is written and unsubmitted.

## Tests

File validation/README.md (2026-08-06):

# Validation plan

Independent cross-checks of the claims in `analysis/`. **Fourteen of the sixteen below have run.**
**Two of them failed**, two are partial, one returned three rows that could not be evaluated at
all, and one found a published number 37 % high.

## Why it exists

This directory was written when `PROVENANCE.md` could point at only two cross-checks — the
Halbach field (analytic vs magpylib) and orbital decay (orbit-averaged vs Cowell RK4) — both
internal, and the field one analytic-against-analytic, so not confirmation by a different
physical method (`OPEN_PROBLEMS.md` E2).

**That has changed, and not uniformly in the project's favour.** A1 put a meshed PDE solve
against K<sub>t</sub> and agreed to 0.03 % after correcting shared quadrature. A4 put CalculiX against the chassis and it passed.
A12 put two independent numerical methods against the array attraction and found the published
value **37 % high**. And **A5 failed**: an independent propagator falsified an invariance claim
that was in the paper's own abstract.

**What has still never happened is a measurement.** Every row below is one model against
another model (E4). Each analysis closes a specific named item.

| # | Analysis | Tool | Closes | Status |
|---|---|---|---|---|
| A1 | Airgap field, 2-D magnetostatic | scikit-fem + gmsh (FEMM substituted) | E1 (2-D half), E2 (partly) | **RUN 2026-07-29**, verdict **PARTIAL**: K<sub>t</sub> agrees to 0.03 % after correcting shared quadrature, two bands missed with causes (P20, P21) |
| A4 | Sled chassis structural | CalculiX ccx 2.21 | **P5, P8** | **RUN 2026-07-28**: as-drawn plate passes all three bands |
| A5 | Orbital lifetime and seeding | GMAT R2022a | E6, hardens x1.80 | **RUN**, verdict **FAIL** on invariance. See [`../docs/RESULTS.md`](../docs/RESULTS.md) |
| A9 | Decay rate against flown CubeSats (TLE history) | Space-Track + numpy | **E6, against reality rather than another model** | **NOT RUN**, blocked by network policy here and re-tested 2026-07-31. **Candidate objects now shortlisted** in the sheet, so this is an afternoon elsewhere |
| A6 | Conjunction probability | scipy 2-D Pc (CARA substituted) | P1 — **not closed** | **CORRECTED 2026-08-03**: fixed-shape claim retracted; current slab bound 4.4e-5, two of five bands, three **VOID**, P1 open |
| A7 | Separation and tip-off | Project Chrono | E7-adjacent | **still specified, not run.** **A7-R RUN 2026-08-05** instead: Chrono is unavailable and the release mechanism is undefined, so the tolerance was computed rather than the rate — the full push may act unbalanced for only **50.7 µs** before the 2 °/s band breaks |
| A8 | Pulse-power chain | ngspice / PySpice | E17 | **RERUN 2026-08-05** as A8-R2 at the corrected point: six of six bands, exit velocity agrees to 0.016 % |
| A10 | Shot against a realistic bank ESR | `motor_model.shot()` | nothing; **opened P26** | **RERUN 2026-08-03**: hard ceiling 68 mohm, five of six bands, one VOID |
| A11 | Regenerative recovery of sled energy | `motor_model.regen_brake()` | nothing; asks what R5 did not | **RERUN 2026-08-03**: 291.4 J recovered, eight of eight bands |
| A12 | Inter-array attraction, two numerical methods | magpylib + surface Maxwell stress | **P17** | **CORRECTED 2026-08-03**: extended stress plane 2680.0 N vs 2686.6 N volume force; five of five bands |
| A13 | Indexing and sled-return attitude disturbance | momentum bookkeeping | **E24** | **CORRECTED 2026-08-03**: transient-rate rows 3/4 FAIL, row 7 VOID; ideal residual rate is zero and the cadence conclusion is superseded |
| A14 | EMI scoping: payload coupling and comms | `drive_electrical` + magpylib | advances **E12**; **opened P34** | **RUN 2026-08-05**, verdict **PARTIAL**: six of eight bands, band 4 **FAIL** at 611x, band 5 VOID. The dominant term is the static magnet field, not the drive |
| A16 | Gen4 finite-stator thrust vs sled station | magpylib | **E27** | **RUN 2026-08-05**: full-overlap thrust reproduces `F_cmd` to 0.000 %; Gen4 reaches **13.390 m/s, 81.7 % of Phase I**, an upper bound |
| A17 | Ripple chirp through the track modes | scipy SDOF | **E23**; **opened P36** | **RUN 2026-08-05**, verdict **FAIL**: 8.18x amplification at the fundamental crossing of the 109 Hz mode, and Q is not the variable that saves it |
| A18 | Brake, magnet eddy, fin transient, launch restraint, standoff | numpy + Miles | **E20, E19, E26, E22**, and E10's analysis half; **opened P37** | **RUN 2026-08-06**: E19/E26/E22 pass, E20 passes only for a 0.4-0.5 T pole field, **E10 FAILS at every Q** |

A10 and A11 are cross-checks of the model against its own physics rather than against an
external tool, which is a weaker class of check and is labelled as one. They are here because each
asks a question no external solver was going to be pointed at: whether the bank can source the
shot at all, and whether the sled's energy has to be thrown away. **A12 is stronger than both** —
its two methods share only the block model of the magnets — and **A6 is weaker than any of them**,
since both its geometry and its covariance come from inside this project.

> **This table was wrong about A1 for a day**, from 2026-07-30 to 2026-07-31: it said "specified,
> not run" while `OPEN_PROBLEMS.md` E1 and `docs/ROADMAP.md` both recorded A1 as run on
> 2026-07-29. The cause is worth keeping, because it is the reason A1 and A5 now carry their
> results inline. **Both run sheets were pure specifications**, with their outcomes living only in
> `OPEN_PROBLEMS.md`, `CHANGELOG.md` and `docs/RESULTS.md`, so a search of `validation/` for
> completed runs found A4, A8 and A10 and missed them. **A run sheet that does not record its own
> result is not a record.** A1 and A5 were written up on 2026-07-31 in the format A4, A8, A10 and
> A11 already used.

A2 (3-D field, end effects) and A3 are not specified here; A1 closes only the 2-D half of
E1, and the 3-D end effects still need a 3-D solver.

## The one rule that makes these tests rather than exercises

**The acceptance band is declared before the analysis runs.** Every run sheet in this
directory states its band up front, and each band is traceable to a current value in
`analysis/results/*.json`. A cross-check whose target is chosen after seeing the answer
proves nothing.

This is not hypothetical here. `docs/FEMM_Run_Sheet.md` was written against ⟨B⟩ ≈ 0.62 T
across the winding gap; the winding-resolved model now computes **0.552 T**, so that
sheet can no longer function as a test and is marked superseded. The replacement sheet
(`analysis/femm/FEMM_RUN_SHEET.md`) had the same problem in its stray-field targets,
they predated the P3 correction, and was fixed on 2026-07-27.

When a band is missed, the outcome is a new P-item, not a quietly widened band.

**And when a band cites an external document, record which document, which revision, and whether
a tighter comparator exists in the same family.** Added 2026-07-31 after **P30**: A7's tip-off
band was set at 5 °/s from the external NRCSD-E, whose publisher calls that figure provisional,
while the internal NRCSD that has actually flown specifies 2 °/s. Nobody picked the easy number
on purpose — it is what happens when a band cites one source and nobody asks what else that source
set contains. **A band may still be tightened before a run**, which is how that one was fixed; it
may never be touched after one.

## Conventions

- Inputs come from what is already committed: `cad/step/gen3/*.step` (Gen3 is current,
  see `cad/README.md`), `cad/parameters.json`,
  `analysis/femm/emocd_cross_section.dxf`. Where a check needs an orbit or a constant, it
  imports from `analysis/*.py` rather than restating the value, see `gmat/build_scripts.py`.
- Outputs land in `validation/results/<analysis>.json` alongside the solver version,
  mesh size, and boundary conditions, the same way `analysis/results/*.json` works.
- A completed run gets a `CHANGELOG.md` entry with cause, before/after, and the P/E item
  it moves.
- `analysis/*.py` stays authoritative until a run closes the relevant item. **Do not
  hand-edit a script to match an FEA result**, record the discrepancy first, decide
  second.

## Licensing

Keep these tools external. CalculiX and Code_Aster are GPL, Elmer is LGPL, and this
repository is MIT, commit input decks and result JSON, never vendored solver code.
Orekit (Apache-2.0), Project Chrono (BSD-3) and pyleecan (Apache-2.0) are permissive.
NASA's CARA tools are MATLAB under a NASA open-source agreement; parts run under Octave,
and the licence should be read before anything is redistributed.

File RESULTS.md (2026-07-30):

# Results, in charts

Everything here is drawn by GitHub from text, no image files. Every value traces to a
field in `analysis/results/*.json`, named under each chart, and nothing has been rounded
in a direction that flatters it.

**These are model outputs.** Nothing in this file has been measured, and only two results
carry an independent cross-check. See [`PROVENANCE.md`](PROVENANCE.md).

---

## Where the energy goes

2796 J leaves the capacitor bank per shot. 547 J of it ends up as payload kinetic energy,
that is the 20 % figure, and it is electrical-to-payload with **no regeneration credit**,
because the sled's 1291 J is dissipated in the eddy brake by design.

```mermaid
pie showData
    title Energy per shot (J), sizing.py energy_closure
    "Sled KE, dissipated in the brake" : 1291
    "Payload KE, the useful output" : 547
    "Copper loss" : 828
    "Converter loss" : 97
    "Auxiliary" : 31
```

Accounted 2795 J against 2796 J drawn, 100.0 % closure, which is the arithmetic check that
the budget has no missing term. Efficiency was 32 % until 2026-07-29; adopting the measured
9.445 kg sled moved it to 20 %, because more of the same mechanical work now goes into a mass
that is braked away, and the longer 157 ms pulse accrues more copper loss. Source: `analysis/results/sizing.json` to `energy_closure`.

An earlier version of this project claimed 52 % efficiency by crediting 55 % of the sled's
energy back as regeneration. That was double-counting: the arrest architecture throws that
energy away. That correction, 52 % to 32 %, is recorded as A25/A27 in
[`INVENTORY.md`](INVENTORY.md).

---

## Why the conjunction claim was reframed

This is the most instructive chart in the repository. It plots the 30-day minimum
satellite-to-stage approach distance against ejection velocity.

```mermaid
xychart-beta
    title "Minimum approach vs ejection velocity, the quantity is not robust"
    x-axis "Ejection velocity (m/s)" [20.00, 20.37, 20.50, 20.65, 21.00]
    y-axis "Minimum approach (km)" 0 --> 70
    line [37.5, 4.6, 56.1, 45.3, 63.4]
```

A ±2.5 % change in velocity moves the answer by more than an order of magnitude, from
4.6 km to 63.4 km. It is a near-resonant beat sample, not a design property. The paper
originally quoted a single figure (45.3 km) as a safety result. It now rests on the
**phase realignment period**: 9.9 days at the current operating point, which is robust,
plus mandatory per-shot collision avoidance and host-stage disposal before first realignment.
The sweep above was computed at the superseded 20.37 m/s point and is kept as the evidence
for P1: the fragility is a property of the beat geometry, not of any one velocity.

Source: the P1 sweep table in [`OPEN_PROBLEMS.md`](OPEN_PROBLEMS.md), computed by
`analysis/astro.py` `conjunction()`. `validation/A6_conjunction_cara.md` specifies the
quantitative replacement, probability of collision, which integrates over the covariance
instead of sampling one geometry.

---

## Payload family

Exit velocity is force-limited, so heavier classes go slower at lower acceleration. Only
the 3U case is designed; 6U and 12U are arithmetic from the same thrust constant, with no
mechanism or cassette behind them (`OPEN_PROBLEMS.md` E9).

```mermaid
xychart-beta
    title "Exit velocity by payload class (m/s)"
    x-axis ["1U", "3U", "6U", "12U"]
    y-axis "Exit velocity (m/s)" 0 --> 20
    bar [18.5, 16.5, 14.5, 13.1]
```

```mermaid
xychart-beta
    title "Acceleration on the satellite (g), 25 g qualification limit"
    x-axis ["1U", "3U", "6U", "12U"]
    y-axis "Acceleration (g)" 0 --> 25
    bar [13.4, 10.7, 8.3, 6.7]
```

Every class now sits well inside the 25 g qualification limit, the 1U case peaks at 13.4 g,
against 23.4 g before the sled mass was measured. The machine is no longer
acceleration-limited but **thrust-and-mass limited**, so more than half the qualification
margin goes unused and recovering velocity means removing mass or raising current, not
shortening the stroke. Source:
`analysis/results/motor_results.json` to `family`.

---

## Seeding: the actual value proposition

Time to spread a constellation 30° apart, by ejection velocity, against the
differential-drag baseline.

```mermaid
xychart-beta
    title "Days to 30 degrees of phase separation"
    x-axis ["EMOCD 10 m/s", "EMOCD 5 m/s", "EMOCD 2 m/s", "Differential drag"]
    y-axis "Days" 0 --> 28
    bar [1.4, 2.8, 6.9, 25.0]
```

Source: `analysis/results/astro_results.json` to `seeding_days`. **Caveat worth reading:**
the 25-day comparator is a model output of `astro.py`, not a measurement. Foster et al.
published *flown* differential-drag phasing results for 12 Planet Labs CubeSats at 510 km;
replacing the modelled baseline with the measured one is the cheapest credibility
improvement available to this project (`docs/RELATED_WORK.md`).

---

## Stray field falloff

Sets the magnetic keep-out for satellites still in the cassettes.

```mermaid
xychart-beta
    title "Stray field behind the array back face (mT)"
    x-axis "Distance (mm)" [10, 20, 50]
    y-axis "Field (mT)" 0 --> 25
    line [22.7, 4.3, 0.4]
```

Source: `analysis/results/field_verification.json` to `stray_field`. The 20 mm and 50 mm
values were wrong in the published paper (4.7 and 1.0 mT) and were corrected against the
script, P3, logged in [`CHANGELOG.md`](CHANGELOG.md) as P2-03. Far-field values are small
differences of large numbers and remain the least trustworthy row here.

---

## The sled mass conflict: settled 2026-07-29

Two estimates of the same part disagreed by 94 %, and the headline exit velocity hung off
which one was right. **The measurement won, and the rule that decided it was written first.**

```mermaid
xychart-beta
    title "Sled mass estimates (kg) against the A4 decision thresholds"
    x-axis ["Parametric", "A4 lower bound", "A4 upper bound", "CAD, measured"]
    y-axis "Mass (kg)" 0 --> 10
    bar [4.86, 5.35, 6.80, 9.445]
```

The two middle bars are **not measurements**: they are the decision rule declared in
[`validation/A4_sled_structural.md`](validation/A4_sled_structural.md) before the analysis
runs:

| Outcome | Consequence declared in advance | |
|---|---|---|
| ≤ 5.35 kg | Parametric model stands. 20.37 m/s holds, P5 and P8 close | |
| 5.35-6.80 kg | Neither estimate right. Scripts move, then the paper | |
| **≥ 6.80 kg** | **The headline changes and the paper changes materially** | **fired** |

Fixing the thresholds in advance was the point, because after the run the temptation is to
pick whichever threshold preserves the nicer number. The measurement came in at **9.445 kg**,
well past the top band; A4 then ran and found the drawn plate passes all three structural
bands, so nothing forces a lighter chassis either. `analysis/` moved first and the paper
followed, the first time a script value has changed in this project.

What it cost: exit velocity 20.37 to **16.54 m/s**, efficiency 32 % to **20 %**. What it did
not cost: the lifetime multiplier fell only x1.80 to **x1.62**, because lifetime is a weak
function of Δv. The mission case survives considerably better than the machine spec does.

---

## Validation status

```mermaid
flowchart LR
    subgraph SPEC["Specified, not run"]
        A1["A1 · FEMM<br/>airgap field"]
        A4["A4 · CalculiX<br/>sled chassis"]
        A6["A6 · NASA CARA<br/>conjunction Pc"]
        A7["A7 · Chrono<br/>separation, tip-off"]
        A8["A8 · ngspice<br/>pulse power"]
    end
    subgraph RUN["Run - GMAT R2022a"]
        A5["A5 · GMAT<br/>lifetime, seeding"]
    end
    A1 --> E1["E1 · 3-D field closure"]
    A1 --> E2["E2 · no FEA of anything"]
    A4 --> P5["P5 · sled mass"]
    A4 --> P8["P8 · exit velocity"]
    A5 --> E6["E6 · absolute lifetimes"]
    A5 --> P16["P16 · invariance falsified"]
    A6 --> P1["P1 · conjunction claim"]
    A7 --> E7["E7 · dispersion assumptions"]
    A8 --> E17["E17 · pulse chain unmodelled"]
```

Six analyses, each with its acceptance band declared before the run. Progress so far:

| Analysis | Status |
|---|---|
| A1 airgap field | `░░░░░░░░░░` specified |
| A4 sled chassis | `████████░░` **run, as-drawn plate passes all 3 bands**; lightest-chassis question open |
| A5 lifetime & seeding | `████████░░` **run, FAIL (P16), and now superseded: it was propagated at 20.37 m/s (P19)** |
| A6 conjunction Pc | `░░░░░░░░░░` specified |
| A7 separation & tip-off | `░░░░░░░░░░` specified |
| A8 pulse-power chain | `████████░░` **run, all bands met, 2 findings; netlist still at the old operating point (P19)** |

## GMAT cross-check (A5): first real validation output

GMAT R2022a was installed and run headless. This is the first number in this project
produced by something other than its own scripts.

> **Read this section as history, not as current validation.** Every GMAT run below was
> propagated at **20.37 m/s**, the rated velocity before the measured sled mass was adopted
> on 2026-07-29. The current point is 16.54 m/s and the script multiplier is x1.62, so the
> absolute numbers here no longer describe the design. **What does survive is the
> falsification**, P16 is about the shape of the model, not the velocity, and a uniform
> density scale cannot move a ratio at any Δv. Re-running A5 is scheduled in
> [`ROADMAP.md`](ROADMAP.md); the staleness is logged as P19.

### Decay rate over a bounded 30-day window

```mermaid
xychart-beta
    title "Baseline orbit semi-major axis, GMAT vs astro.py (km)"
    x-axis "Days from epoch" [0, 5, 10, 15, 20, 25, 30]
    y-axis "Semi-major axis (km)" 6810 --> 6832
    line [6828.14, 6823.25, 6815.45, 6817.31, 6825.00, 6819.62, 6812.58]
    line [6828.14, 6827.54, 6826.95, 6826.34, 6825.73, 6825.11, 6824.49]
```

First line GMAT, second `astro.py`. The GMAT curve wanders because **reported SMA is
osculating**, short-period J2 and lunisolar terms run 12.2 km peak to peak here, several
times the decay over the whole window. `astro.py` integrates mean elements, so its curve is
smooth. Differencing the endpoints of the two would be meaningless; the honest comparison is
the fitted rate:

| | Decay rate | Method |
|---|---|---|
| GMAT | **−0.1618 km/day** | least squares over 31 daily samples, residual RMS 4.24 km |
| `astro.py` | **−0.1216 km/day** | 30-day Cowell integration, `cowell_sma_after()` |
| Ratio | **1.33x** | GMAT decays faster |

**A 33 % difference in absolute decay rate is not a failure**, and E6 says so in advance:
`astro.py` uses a static exponential atmosphere at "mean activity" while GMAT uses MSISE90
at F10.7 = 150, and those are not the same thing. The claim this project defends is the
ratio between boosted and unboosted lifetimes, not the years.

An internal consistency check fell out of it: a 1.33x faster decay predicts the
high-activity case reaching 120 km at 190 / 1.33 ≈ 143 days. GMAT's full run gives
**144.5 days**. The bounded window and the full decay agree with each other.

### Full decay runs: the x1.80 claim, checked, and the invariance falsified

All three activity levels propagated to the 120 km floor. Two pass. The third does not, and
it takes the abstract's claim with it.

```mermaid
xychart-beta
    title "Lifetime multiplier by solar activity, band is 1.71 to 1.89"
    x-axis ["High F10.7 250", "Mean F10.7 150", "Low F10.7 70", "astro.py claim"]
    y-axis "Multiplier" 1.5 --> 2.2
    bar [1.7302, 1.7750, 2.0739, 1.80]
```

| Solar activity | Baseline | Boosted | Multiplier | vs x1.80 | Band ±5 % |
|---|---|---|---|---|---|
| High (F10.7 = 250) | 144.5 d | 250.0 d | **1.7302** | −3.88 % | pass |
| Mean (F10.7 = 150) | 429.9 d | 763.1 d | **1.7750** | −1.39 % | pass |
| **Low (F10.7 = 70)** | 2359.1 d | 4892.4 d | **2.0739** | **+15.21 %** | **FAIL** |

**Spread across the three: 18.48 %, against the ≤5 % invariance band declared before the
run. A5's verdict is `FAIL`.**

The point value is not what died here. At mean and high activity an independently
implemented force model, MSISE90, 20x20 gravity, lunisolar third bodies, SRP, RK89,
reproduces x1.80 to within 4 %. What died is the claim that the ratio is *invariant* across
solar activity, which is the property the paper's Limitations section nominates as "the
defensible result" and the abstract states outright.

### Why `astro.py` could never have found this

The reason the project believed the ratio was invariant is visible in one sweep. `astro.py`
models solar activity as a uniform multiplicative scale on density. Drive that scale over a
**40x range** and the multiplier does not move:

```mermaid
xychart-beta
    title "astro.py multiplier vs density scale, invariant by construction"
    x-axis "Density scale factor" [0.25, 0.5, 1.0, 2.5, 5.0, 10.0]
    y-axis "Multiplier" 1.79 --> 1.81
    line [1.7992, 1.7991, 1.7989, 1.7982, 1.7971, 1.7968]
```

Constant to 0.1 % across a factor of forty. That is not a physical result, a uniform
density factor divides both lifetimes by the same number, so the ratio cancels. The model
cannot report anything else. MSIS instead changes the *shape* of the density, altitude
profile with F10.7, and because the boosted orbit's apogee sits some 37 km above the
baseline's, the two orbits sample that changed shape differently. The ratio then moves:
1.73 at high activity, 2.07 at low.

Reproducible from `analysis/astro.py` `lifetime()` with no edits to the script.

### What else did not agree

The absolute lifetimes, and **the error changes sign across the range**: GMAT is 2.5x
longer than `astro.py` at low activity, 9 % shorter at mean, 23 % shorter at high. E6
predicted absolute disagreement in advance; it did not predict a sign change, which is the
same profile-shape effect seen from the other side.

Verdict, force models, per-level numbers and run metadata:
[`validation/results/A5_astro.json`](validation/results/A5_astro.json). Full write-up as
[`OPEN_PROBLEMS.md`](OPEN_PROBLEMS.md) **P16**.

> **The parser earned its keep here.** Its first run read a decay file GMAT was still
> writing, took the partial decay as final, and produced a confident `FAIL`. It now refuses
> to report a multiplier unless the run actually reached the 120 km floor. A validation
> harness that reports a failure it cannot substantiate is worse than no harness.

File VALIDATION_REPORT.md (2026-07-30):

# Validation report: 2026-07-28

Every headline claim in this repository, and what independently checking it produced.

Four things were actually run: the analysis scripts were re-executed from a clean copy,
GMAT R2022a propagated the orbits, ngspice simulated the pulse chain, and the Gen3 sled
geometry was measured against material densities. Three planned analyses were **not** run
and are listed as such, nothing here is inferred from an analysis that did not happen.

**Two findings change numbers the project publishes.** Both are at the bottom of this file
and in `OPEN_PROBLEMS.md`.

---

## 1. Does the repository reproduce itself?

**Validated.** All five scripts in `analysis/` were copied to a clean directory, run with
an empty `results/`, and their output compared field by field against the committed JSON.

| | |
|---|---|
| Values compared | **173** |
| Identical | **173** |
| Differing | **0** |

Every number in `analysis/results/*.json` (and therefore every headline figure) is
regenerable from the committed scripts today. This is the claim `D12` makes, and it holds.

---

## 2. Astrodynamics: GMAT R2022a (A5)

GMAT was installed and run headless: MSISE90 atmosphere, 20x20 gravity, Luna and Sun as
point masses, SRP on, RK89. Independently implemented force models, not a second pass of
the same code.

### The x1.80 multiplier holds at two activity levels. **Its invariance does not.**

All three runs are complete.

| Solar activity | GMAT baseline | GMAT boosted | Multiplier | vs x1.80 | Band ±5 % |
|---|---|---|---|---|---|
| High (F10.7 250) | 144.5 d | 250.0 d | **1.7302** | −3.88 % | pass |
| Mean (F10.7 150) | 429.9 d | 763.1 d | **1.7750** | −1.39 % | pass |
| **Low (F10.7 70)** | **2359.1 d** | **4892.3 d** | **2.0739** | **+15.21 %** | **FAIL** |

**Invariance spread across the three: 18.48 % against a ≤5 % band. A5's verdict is FAIL.**

An earlier version of this section reported 2.55 % and called the invariance confirmed. That
was computed from the two levels that had finished at the time, and it was wrong, recorded
here rather than quietly replaced.

### Why the two codes disagree, tested rather than guessed

`astro.py` models solar activity as a **uniform multiplicative scale on density**. Sweep
that scale over a factor of forty and the multiplier does not move:

| density scale | 0.25 | 0.5 | 1.0 | 2.5 | 5.0 | 10.0 |
|---|---|---|---|---|---|---|
| multiplier | 1.7992 | 1.7991 | 1.7989 | 1.7982 | 1.7971 | 1.7968 |

Constant to 0.1 % across 40x. **That is not a physical result, it is arithmetic.** A
uniform density factor divides both lifetimes by the same number, so the ratio survives by
construction of the model. The invariance was never tested by the sweep that claims to
demonstrate it.

MSIS changes the *shape* of the density-altitude profile as F10.7 varies, not just its
magnitude. The boosted orbit carries apogee about 37 km higher than the baseline, so the two
orbits sample the profile differently and the ratio moves: 1.73 at high activity, 2.07 at
low.

**What survives:** the x1.80 point value at mean and high activity, comfortably. **What does
not:** the claim that it is invariant across solar activity, which is stated in the paper's
abstract and which the paper's own Limitations section nominates as "the defensible result".
Recorded as P16.

### Absolute lifetimes: **not confirmed, as expected**

GMAT decays faster than `astro.py` at high and mean activity: 144.5 days against 190 at high
activity. The bounded 30-day window measured the same thing independently, fitted rates of
−0.1618 km/day (GMAT) against −0.1216 (`astro.py`), a factor of **1.33**. The two agree with
each other: 190 ÷ 1.33 ≈ 143 days.

E6 said absolute lifetimes carry severalfold uncertainty and that only the ratio is
defensible. That is now demonstrated rather than asserted.

The disagreement changes sign with activity, which is the same story from another angle:

| | `astro.py` | GMAT | |
|---|---|---|---|
| Low activity | 2.61 yr | **6.46 yr** | GMAT 2.5x longer |
| Mean | 1.30 yr | 1.18 yr | GMAT 9 % shorter |
| High | 0.52 yr | 0.40 yr | GMAT 23 % shorter |

A model whose error changes sign across its input range is not off by a calibration factor,
it has the wrong shape.

Detail: [`validation/results/A5_astro.json`](validation/results/A5_astro.json).

---

## 3. Pulse-power chain: ngspice (A8)

The mechanical ODE was rebuilt in analogue-computer form so SPICE integrates it with a
different scheme (trapezoidal) than `motor_model.py` (forward Euler, dt = 1e-4), while the
electrical side is a real circuit: 6 F bank, 96 V, series ESR, load drawing P/V at the
terminal.

| Quantity | `motor_model.py` | ngspice | Deviation | Band | |
|---|---|---|---|---|---|
| Exit velocity | 20.372 m/s | 20.366 | −0.03 % | ±10 % | pass |
| Pulse duration | 127.7 ms | 127.66 | −0.03 % | ±10 % | pass |
| Peak current | 391.7 A | **415.2 A** | +5.98 % | ±10 % | pass |
| Bank sag | 4.88 % | 5.06 % | +0.18 pts | ±1.5 pts | pass |
| Energy drawn | 2634 J | 2729 J | +3.59 % | ±5 % | pass |

Two different integrators landing within 0.03 % on exit velocity is a real check of the
shot model's arithmetic. All five declared bands met, **and two findings fell out anyway.**

Detail: [`validation/results/A8_pulse.json`](validation/results/A8_pulse.json), netlist at
[`validation/spice/emocd_shot.cir`](validation/spice/emocd_shot.cir).

---

## 4. Sled mass: measured from the Gen3 CAD (A4, partial)

Exact solid volumes from the OpenCASCADE kernel, multiplied by material densities. The
magnet density (7500 kg/m³) is the repo's own, from `sizing.py`.

| Body | n | cm³ each | Material | kg |
|---|---|---|---|---|
| Chassis plate 488x140x6 | 2 | 409.9 | Ti-6Al-4V | 3.632 |
| Halbach array 340x90x8 | 2 | 244.8 | NdFeB | 3.672 |
| Backstop 8x140x100 | 1 | 112.0 | Ti-6Al-4V | 0.496 |
| Chassis web 488x6x28 | 2 | 82.0 | Ti-6Al-4V | 0.727 |
| Brake fin 120x80x4 | 1 | 38.4 | Copper | 0.344 |
| Roller arm 40x16x20 | 4 | 12.8 | Ti-6Al-4V | 0.227 |
| Roller Ø30x16 | 4 | 11.3 | 440C steel | 0.348 |
| **Total as drawn** | | | | **9.445** |

**The method reproduces the existing claim exactly.** Fed 7.50 kg, the shot model returns
17.87 m/s, the 17.88 m/s that P8 states. Fed the measured 9.445 kg, it returns **16.53 m/s
at 10.7 g and 19.6 % efficiency**.

What this is not: it is not the structural FEA A4 specifies. It measures the sled *as
drawn*, with solid plates and no lightening pockets. A real design would pocket them. The
stiffness question (the lightest chassis that holds the airgap to ±0.05 mm) remains open.

---

## 4b. Sled chassis structural: CalculiX (A4)

Quadratic-tet FE of one 488x140x6 mm chassis plate lifted straight out of the Gen3 STEP,
29,312 nodes, loaded with the 3672 N Maxwell attraction over the 340x90 mm magnet footprint
from `sizing.json`. Support at the web lines is bracketed, pinned (lower bound on
stiffness) and clamped (upper bound), because the real joint is between the two and
reporting one number would be a choice dressed as a result.

| Band, declared before the run | Result | |
|---|---|---|
| Airgap closure ≤ 0.025 mm per plate | **0.0194 mm** pinned, 0.0160 clamped | pass, 78 % of budget |
| Von Mises ≤ 587 MPa | **33.7 MPa** | pass, **17x margin** |
| First mode > 200 Hz | **3408 Hz** | pass, 17x |

**The chassis as drawn is sound.** It is nowhere near strength-limited and comfortably
inside the deflection budget.

> **The load itself was never checked, and it is 37 % high, P17, found 2026-07-29.**
> The 3672 N comes from a flat-plate Maxwell-stress formula in `sizing.py`: a uniform
> `B²/2μ₀` at a 0.55 T mean face field over the footprint. Recomputing the same force with
> `magpylib.getFT()`, which meshes the blocks and integrates the field gradient in 3-D on the
> repo's own array geometry, converges to **2686.6 N**: deltas halving cleanly through a
> (14,14,14) mesh and independent of the finite-difference step from 1e-5 to 1e-8. The reason
> is structural: Maxwell stress needs mean(B²), the formula uses mean(B)², and
> mean(B²) ≥ mean(B)² for any non-uniform field, so the analytic form must overestimate a
> Halbach face. **This does not reverse anything above**: the real load is lighter, so every
> band passed with more margin than reported, not less. What it does mean is that A4's input
> was taken on trust, which is the one thing this report is supposed to stop.
> Reproduce: `python3 validation/magpylib/check_inter_array_force.py`.

**And that is why the velocity problem does not go away.** A4 was supposed to decide whether
the sled could be lighter. The answer it gives is that the drawn plate already meets the
constraint, so nothing structural forces it to be heavier, but equally, nothing here makes
it lighter. Uniform thinning is nearly worthless: deflection scales as 1/t³, so the budget
is spent at about 5.5 mm, which saves 0.30 kg of 9.445 and moves exit velocity from 16.53 to
roughly 16.7 m/s. Genuine reduction needs a rib-stiffened redesign, section depth enters as
the square, and **no analysis anywhere has evaluated one.** The 60 % pocketing row in
`docs/DESIGN_OPTIONS_exit_velocity.md` is unsupported until someone does.

Idealisations, stated because they bound the result: one plate rather than the assembled
box; web attachment as two support lines; load applied as equal nodal forces (total exact,
local distribution approximate); bonded magnets not modelled, which is conservative; static
attraction only, no launch or arrest loads.

## 5. Not run, and why

| Analysis | Status |
|---|---|
| **A1** airgap field, magnetostatic FEA | **RUN 2026-07-29, thrust band met at ratio 1.001.** See section 5. |
| **A4** sled structural | **Run**: see section 4b. Mass measured, stiffness/stress/modal computed. What remains is the optimisation question: the lightest chassis meeting the constraint, which needs a rib-stiffened study. |
| **A6** conjunction P<sub>c</sub> | **Not run.** Needs a covariance that does not exist for an unflown satellite (E18), and the CARA tools are MATLAB. |
| **A7** separation and tip-off | **Not run.** Recorded here as "Project Chrono is not installable", **that verdict is now in doubt**: `pychrono` ships on conda-forge rather than PyPI and lists linux-64, so a failed `pip install` is the likely cause. Retry before treating A7 as blocked. Tip-off remains a model output with no multibody model behind it, and the acceptance band it would be judged against may itself be mis-sourced (`docs/LANDSCAPE.md`). |
| Thermal, contamination, EMC, host stage | Unchanged, E5, E11, E12 stand. |
| Anything at all in hardware | **Nothing has been built, fired, or measured.** E4 stands, and no amount of this changes TRL 2-3. |

---

## Findings

### F1: The Gen3 sled as drawn is 9.45 kg, above both existing estimates, **HIGH**

`mass_properties.py` assumes 4.86 kg. P5 quotes the CAD at ~7.50 kg. Measuring the Gen3
solids gives **9.445 kg**, which drives exit velocity to **16.53 m/s**: below the 17.88 m/s
that P8 already flags as provisional.

A4's pre-declared decision rule says a mass at or above 6.80 kg means "17.88 m/s becomes the
headline and the paper changes materially". The measurement lands well beyond that
threshold. It does not settle the design question, pocketed plates would weigh less, and
the stiffness constraint is unevaluated, but **whichever way the FEA goes, 20.37 m/s is not
supported by the geometry that currently exists.** Recorded as P15.

### F2: Quoted bank sag is state-of-charge, not terminal voltage, **MEDIUM**

`motor_model.py` computes sag as the capacitor's charge depletion (4.88 %) and models no
ESR. With the 12 mΩ ESR the terminal voltage droops to 86.16 V at end of stroke: a **10.25 %
total sag**, more than double the published figure. The servo-headroom argument behind the
0.027 m/s dispersion claim is stated against the smaller number. Recorded under E17.

Related: ∫I² dt over the shot is 8008 A²s. At 12 mΩ that is 96 J of ESR loss, against the
`Q_esr = 160 J` default in `sizing.py`. The two are consistent only at ~20 mΩ. E17 noted that
160 J had no second number against it; this is the second number.

*(The 12 mΩ itself appears only in `docs/EMOCD_Computation_Results_C1-C10.md`, which is
superseded. No current script defines a bank ESR at all, which is part of the problem.)*

---

## 5. Airgap field: 2-D magnetostatic FEM (A1)

**The most important validation this project has run**, because K<sub>t</sub> = 11.22 N per
kA/m sets exit velocity, efficiency and every downstream astrodynamic number, and until now
it had only ever been checked *analytic against analytic*. The closed-form travelling-wave
model and magpylib both superpose analytic solutions for uniformly magnetised blocks. Neither
solves a field equation.

A1 does. Vector-potential magnetostatics on a triangular mesh (scikit-fem P1, gmsh),
**141 k elements**, 0.6 mm airgap mesh, Az = 0 on a 500 mm box. Geometry and magnetisation
imported from `motor_model.py` so the two cannot describe different machines; sampling windows
copied from `verify_field.py` so they are compared at the same places.

| Quantity | FEM | Reference | Ratio | Band | |
|---|---|---|---|---|---|
| Midgap peak | 0.6947 T | 0.6942 | **1.001** | ±5 % | pass |
| Winding mean \|B\| | 0.5523 T | 0.5518 | **1.001** | ±5 % | pass |
| **Thrust at 140 kA/m** | **1571.9 N** | **1570.8** | **1.001** | **±10 %** | **pass** |
| Stray at 10 mm | 26.3 mT | 22.7 | 1.160 | factor 1.5 | pass |
| Stray at 20 mm | 4.91 mT | 4.3 | 1.142 | factor 1.5 | pass |
| Array-surface peak | 1.4641 T | 0.7714 | 1.898 | ±5 % | **miss, P20** |
| Stray at 50 mm | 0.929 mT | 0.4 | 2.322 | factor 2 | **miss, P21** |

**K<sub>t</sub> = 11.228 N per kA/m against 11.22, and ripple 1.25 % against 1.26 %.** An
independently implemented method (a meshed PDE solve rather than superposition) reproduces
the number every headline in this project descends from, to **0.07 %**.

### Both misses have identified causes, and neither is a model error

**P20, the run sheet's reference was wrong for that row.** The array-surface band was declared
against `analytic_B0_surface_T` = 0.7714 T, the fundamental of a **single** array's wave. Any
measurement at that plane in a double-sided machine includes the opposing array, worth
`B0·exp(-k·GAP)` = 0.160 T there. Correct reference: **0.9317 T**. The FEM's fundamental is
**0.9312 T, ratio 0.9994.** The row failed as declared and the model is right; both are
recorded, and **the band was not widened**: `A1_field_femm.md` stands exactly as written on
2026-07-27, because a run sheet edited after seeing results is worth nothing.

**P21, 2-D cannot test the far field.** The FEM has infinite depth; the array is 90 mm deep.
At 10 and 20 mm the observation distance is small against that and the two agree. At 50 mm it
is comparable, a finite source falls off faster, and 2-D necessarily overestimates. Converged,
not noise: 0.93 mT across boxes from 0.5 to 0.8 m and meshes from 32 k to 141 k elements. The
magpylib reference models finite blocks exactly and is the better number here.

### What was checked before concluding

The run sheet names air-box size as the first suspect on a miss, so it was tested first.
Box 0.20 to 0.80 m moves midgap by 0.2 %, winding by 1.3 %, **K<sub>t</sub> by 0.07 %**: all
converged. Mesh 32 k to 141 k elements moves K<sub>t</sub> by 0.2 %. The stray rows move with
both, which is why their bands were declared loose and why the 50 mm row needed a physical
explanation rather than a numerical one.

Detail: [`validation/results/A1_femm.json`](validation/results/A1_femm.json). Script:
[`validation/fem/a1_airgap_field.py`](validation/fem/a1_airgap_field.py).

> **Note on the solver.** The run sheet names FEMM, which is Windows-only and was not
> available. This is a meshed differential-FEM solve of the same 2-D problem, which is what E2
> actually asks for, recorded as what it is rather than presented as FEMM.
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

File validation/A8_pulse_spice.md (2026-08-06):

# A8: Pulse-power chain (ngspice / PySpice)

**Closes:** `OPEN_PROBLEMS.md` **E17**.

The supercapacitor bank, the SiC bridge, and the winding are currently modelled
analytically inside `motor_model.py` and `sizing.py`, lumped R, ideal switching, no
device dynamics. A circuit simulation is a genuinely different method and costs an
afternoon, not a lab. It is the cheapest independent check in this directory.

## Inputs (all committed)

- Bank: **6.0 F selected** (5.97 F required), **32 cells in series**, 3.0 V / 190 F per
  cell, `analysis/results/sizing.json` `capacitor`
- Rail 96 V, series resistance 12 mΩ, per `sizing.py`
- Winding and drive as used in `motor_model.py` `shot()`
- Shot profile: force command 1413 N, 127.7 ms pulse

## Acceptance band (declared 2026-07-27, before running)

Reference values from `analysis/results/motor_results.json` and `sizing.json` as committed
at `40e09f9`.
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

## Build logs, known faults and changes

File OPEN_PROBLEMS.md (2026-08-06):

# Open problems, known errors, and the fix list

Two categories: **P-items are errors in the currently published paper** and should be
fixed first. **E-items are genuinely unsolved engineering.**

Last reviewed 2026-08-05.

---

## P: Errors found while building this repo (paper does not match its own scripts)

> **STATUS (2026-07-23): P1, P4 all RESOLVED in `paper/paper.tex`.** Fixes, causes and
> before/after values are logged in `CHANGELOG.md` (entries P2-01, P2-04). The items are
> kept in full below for the audit record. Two related defects found in the process were
> also fixed: the F06 conjunction figure was regenerated at the rated velocity, and a
> stale `astro.py` docstring value was corrected, both logged in `CHANGELOG.md`.

### P1. Conjunction minimum is wrong AND not a robust quantity: HIGH PRIORITY
**RESOLVED 2026-07-23, see CHANGELOG.md P2-01.**
The paper states a 30-day minimum satellite-to-stage approach of **45.3 km**. That
figure was computed at **20.65 m/s**, the superseded operating point. At the paper's
own rated velocity of **20.37 m/s**, `analysis/astro.py` gives **4.6 km**.

Worse, the quantity is fragile. Sweeping ejection velocity:

| Î”v (m/s) | min approach (km) |
|---|---|
| 20.00 | 37.5 |
| 20.37 (rated) | **4.6** |
| 20.50 | 56.1 |
| 20.65 (paper's value) | 45.3 |
| 21.00 | 63.4 |

This is a near-resonant beat sample, not a design property. A ±2.5 % velocity change
moves it by more than an order of magnitude.

**Follow-up:** `validation/A6_conjunction_cara.md` specifies the quantitative version,
probability of collision via NASA's CARA tools, which integrates over the covariance
instead of sampling one geometry. The test is whether Pc stays stable across the velocity
sweep that moves minimum distance by an order of magnitude.

> **A6 ran 2026-07-31 in a reduced form and P1 stays open.** Without GMAT, CARA or
> Space-Track there is no real covariance, so a 2-D Pc was computed against `astro.py`'s own
> propagator with an assumed one. **The stability test came back void**: at 14 to 63 km miss
> distances against a hundreds-of-metres covariance, Pc underflows double precision, and a
> spread of zeros is not a number.
>
> **What the run found instead is better than what it was looking for.** Pc has a maximum over
> covariance scale — a covariance wide enough to reach a 14.5 km miss is too diffuse to put
> probability inside a 5 m disc — and that maximum is **3.7e-8, some 2700x below the 1e-4
> anyone would act on, for any covariance whatsoever.** So Pc is not *robust* where distance is
> fragile; it is **irrelevant**, bounded far below any action threshold.
>
> **This does not close P1**, because a bound is not a probability. It does say the paper's
> current position — the 9.9-day realignment period plus mandatory per-shot COLA, and no
> minimum-distance claim — is the right one, and is now supported rather than merely honest.

**Fix:** stop quoting a specific minimum distance as a safety result. Reframe around
what IS robust: the ~8.1-day phase realignment period, and the mitigation of disposing
of the host stage before the first realignment. State plainly that per-shot COLA is
mandatory because the approach geometry is sensitive to exact ejection velocity.

### P2. Peak current is stale: MEDIUM PRIORITY
**RESOLVED 2026-07-23, see CHANGELOG.md P2-02.**
Paper says **323 A**. That belongs to the superseded 130 kA/m point. At the rated
140 kA/m, `motor_model.py` gives **392 A**. Fix the paper, and check that the SiC
device derating discussion still holds at the higher current (it should, 96 V rail,
1200 V devices, but the current rating of the bridge and busbars needs restating).

### P3. Far-field stray values don't reproduce exactly: LOW PRIORITY

> **QUANTIFIED 2026-08-05 by `analysis/far_field_sensitivity.py`.** P3's diagnosis was right and
> the size of it was not known. Sweeping `build_field(n_wave)` from 3 to 15 wavelengths against a
> converged reference:
>
> | Station | Deviation at the default n=7 (336 mm) | Converged |
> |---|---:|---:|
> | 10 mm | **0.64 %** | 22.688 mT |
> | 20 mm | 4.36 % | 4.290 mT |
> | 50 mm | **374 %** | 0.104 mT |
>
> **The 10 mm value is converged and the 50 mm value is not remotely.** At n=7 it is 0.49 mT
> against a converged 0.104, and it is still 16 % out at n=13. The paper's 1.0 mT corresponds to
> an array shorter than the CAD's 340 mm. **No 50 mm stray figure in this project should be
> cited**, including the 0.4 mT in `field_verification.json`, until the array length is set to
> the CAD value and the model converged.
>
> This needs no mesh: magpylib's Cuboid is an exact analytic solution for a uniformly magnetised
> block, so the field is already three-dimensional. What was missing was the convergence check.
**RESOLVED 2026-07-23, see CHANGELOG.md P2-03.**
Paper quotes 22.7 / 4.7 / 1.0 mT at 10 / 20 / 50 mm. `verify_field.py` reproduces
22.7 mT at 10 mm exactly but gives 4.3 and 0.4 mT at 20 and 50 mm. Likely sensitivity
to modelled array length (edge effects dominate the far field). The 10 mm value is the
one that sets the keep-out spec, so this is minor, but resolve it before anyone cites
the 20/50 mm numbers.

### P4. Brake fin temperature rise conflates per-shot with per-campaign: MEDIUM PRIORITY
**RESOLVED 2026-07-23, see CHANGELOG.md P2-04.**
The paper states the 0.86 kg copper fin sees "an adiabatic 37 K transient rise" **per
shot**, and later refers to "the adiabatic per-shot rises (0.3 K coil, 37 K fin)".

`analysis/sizing.py` gives 1008 J into 0.86 kg of copper = **3.0 K per shot**. The 37 K
figure is the *full 12-shot campaign* total if the fin never radiated between shots
(12 x 1008 J / 331 J/K = 36.5 K).

The design is therefore *less* thermally stressed than the paper claims, but the number
as written is wrong and internally inconsistent.

**Fix:** state 3.0 K per shot, and 37 K as a bounding campaign-adiabatic case that
radiation between shots relieves. Same correction applies to the coil: 0.28 K per shot,
3.3 K campaign.

---

## P: CAD reconciliation and packaging (found in the 2026-07-23 Fusion 360 CAD build)

> These arose when the parametric design was taken into CAD across nine Fusion documents.
> The CAD is authoritative for **geometry and fit only**; `analysis/*.py` remains
> authoritative for **mass and performance** until FEA closes the open items. All
> geometry values below are traceable to `cad/parameters.json`. **No number in
> `analysis/*.py` or `paper/paper.tex` has been changed** on the strength of the CAD.

### P5. CAD sled mass contradicts the parametric assumption: RESOLVED 2026-07-29
> **RESOLVED.** `motor_model.M_SLED` and `sizing.M_SLED` now carry the CAD-derived **9.445 kg**
> (P15), not the 4.86 kg parametric estimate. A4 ran, the drawn plate passed all three
> structural bands, and the measurement fell in the decision rule's ≥ 6.80 kg branch, so the
> rule resolved this rather than a judgement call. **Caveat carried forward:** 9.445 kg is
> the as-drawn, unpocketed geometry and A4 reports a 17x stress margin, so a rib-stiffened
> chassis would recover mass. Designing one is the open successor to this item
> (`docs/ROADMAP.md`), and it is tracked under E2 rather than here.

Original item follows for the audit trail.

> **UPDATE 2026-07-28, A4 structural leg has RUN (CalculiX).** The as-drawn 6 mm plate
> passes every declared band: 0.0194 mm airgap closure against a 0.025 mm per-plate budget,
> 33.7 MPa against 587 allowable, first mode 3408 Hz against >200. So there is **no
> structural argument for the chassis being lighter than drawn**, a lighter one has to be
> designed (rib-stiffened), not assumed. Combined with P15's CAD-derived 9.445 kg, the decision
> rule's ≥6.80 kg branch stands and the machine as it exists delivers **16.53 m/s**.
The first-pass Fusion sled (6 mm Ti-6Al-4V chassis, stiffness-driven by the ±0.05 mm gap
tolerance under 3.7 kN inter-array attraction — 2.69 kN since A12 — **no structural FEA behind it**) implies a
sled mass of **~7.50 kg**. `analysis/mass_properties.py` assumes **4.86 kg**, which
`motor_model.py` hard-codes as `M_SLED` and which sets the headline exit velocity. Both
are estimates (one CAD-geometric, one parametric-solid) and neither is FEA-verified. Do
not change the scripts until analysis A4 closes the chassis, specified with a
pre-declared decision rule in `validation/A4_sled_structural.md` (CalculiX or
Code_Aster, both free, both read `cad/step/gen3/EMOCD_Sled_Gen3.step`). Source:
`cad/parameters.json` (sled group, `PROVISIONAL_PENDING_FEA`).

### P6. Payload seating / orientation: RESOLVED (by CAD, 2026-07-23)
Resolved via the rail interface: the 3U payload now models the four CubeSat Design
Specification corner rails (8.5 mm, `cad/parameters.json` `payload_3u`), which fix seating
and orientation against the sled cradle. No further action.

### P7. Brake sits past the release point: geometry / ConOps
The eddy brake occupies **x = 1530-1740 mm**, beyond the **1500 mm** satellite release
point, on an 1800 mm longeron. The sled runs on into the brake after the payload departs
consistent with the fire-then-arrest ConOps, but it forces the track and enclosure to
extend past release, which drives the envelope length (see P9). Source:
`cad/parameters.json` (brake, track).

### P8. Exit velocity provisionally 17.88 m/s pending sled structural FEA: RESOLVED 2026-07-29
> **RESOLVED, and not at 17.88 m/s.** That figure came from the 7.50 kg CAD estimate. The
> CAD-derived mass is 9.445 kg, so the rated velocity is **16.537 m/s at 10.7 g**, now
> propagated into `analysis/`, `paper/paper.tex`, the figures and every front page. The
> machine is no longer acceleration-limited: at 10.7 g against a 25 g cap it is
> thrust-and-mass limited, which changes what recovering velocity means (mass or current,
> not stroke).

Original item follows for the audit trail.

If the CAD sled mass (P5) holds, exit velocity falls from the script's **20.37 m/s** to a
provisional **~17.88 m/s** (with acceleration ~12.5 g, efficiency ~24 %, recoil
~71.5 N·s, lifetime multiplier x1.68, all CAD-corrected and provisional). **These values
are NOT propagated into `analysis/*.py` or `paper/paper.tex`**; the scripts stay
authoritative until analysis A4 locks the sled mass (`validation/A4_sled_structural.md`,
which fixes in advance which of the two estimates wins at which mass). Do not hard-swap
20.37 to 17.88 anywhere. Source: 2026-07-23 CAD Master Plan; see README headline note.

### P9. Closed envelope exceeds ESPA Grande by ~44%: packaging / host
The closed installed envelope is **1839x 530x 940 mm** (`cad/parameters.json`). The
1839 mm length exceeds ESPA Grande's ~1270 mm longest-dimension class by ~44%, because
the brake lives past the 1500 mm release point and the enclosure spans it. Owner decision
(cannot be made in code): re-scope the host to POEM / custom accommodation (the paper
already leans host-agnostic), or shorten the track / repackage the brake. This supersedes
the earlier 1825x 516x ~1030 mm figure; the height change (1030 to 940) exceeds what skin
thickness explains and is **flagged for re-verification** in `cad/parameters.json`.

### P10. Enclosure, radiator, and packaged avionics absent from the mass rollup: MEDIUM (NEW)
The ninth document (`EMOCD_Enclosure`) adds 2 mm aluminium skins, a 1600x 200x 3 mm
radiator, and equipment bays for the supercapacitor bank, PPU, sequencer, and IMU. **None
have line items in `analysis/mass_properties.py`**, so the 72.3 kg dry-mass rollup is
incomplete. Add line items once masses are estimated (do not alter existing items without
cause). Source: `cad/parameters.json` (`enclosure.mass_note`).

### P11. The corrections may never have reached the submitted paper: RESOLVED 2026-07-29
> **RESOLVED: nothing has been submitted anywhere.** checked 2026-07-29.
> There is no version of record, so P1, P4 are not loose in any published document and no
> corrigendum is needed. `paper/archive/EMOCD_submission_uncorrected.pdf` is a draft build
> whose filename overstates its status, it was never sent.
>
> **This unblocks the paper edits that were batched behind it.** The reason P12 and P16 were
> left untouched in `paper/paper.tex` was that editing the source without rebuilding the PDF
> would split it from a published record. There is no published record. The paper is a draft,
> the only cost of editing it is that the committed PDF goes stale until it is recompiled,
> and that is a normal state for a draft rather than a defect. **Fix P12 and P16 in
> `paper.tex` and rebuild before anything is submitted.**

Original item follows, kept for the audit trail.

`paper/archive/EMOCD_submission_uncorrected.pdf` is a build of the paper that still
carries all four P1, P4 values (323 A, 23 A/mm² at 140 kA/m, 37 K per shot, 45.3 km
conjunction minimum). Its filename says *submission*. If that is genuinely the version
that went to the conference, then P1, P4 are corrected **only in this repository** and the
version of record is still wrong, which is a different situation from the STATUS block
at the top of this file, and one that a corrigendum, not a git commit, has to fix.
**Confirm which build was submitted.** If it was the uncorrected one, decide between
withdrawing, submitting an erratum, or correcting at the camera-ready stage, and record
the outcome here. If the submitted build was in fact compiled from the corrected
`paper.tex`, delete this item and say so in `CHANGELOG.md`.

### P12. The paper contradicts the CAD in two places: RESOLVED 2026-07-29
> **RESOLVED in `paper/paper.tex`.** The Limitations section no longer says masses derive
> from a parametric model rather than detailed CAD; it states what the CAD solid-volume calculation gives and what
> that costs. The ESPA-Grande envelope is no longer asserted as a capability, the
> requirement statement, the Fig. 2 caption and the accommodation section now record 1839 mm
> against the ~1270 mm class and name it an open packaging problem (P9). The mounting-interface
> statements were true and are unchanged. **The committed PDF still predates these edits**;
> see `paper/README.md`.

Original item follows for the audit trail.

Found while sweeping the repository for stale values. Both are prose claims, not computed
numbers, and neither has been changed in `paper/paper.tex`:

1. **Limitations (Sec. XV) says "Masses derive from a parametric solid model, not detailed
   CAD."** That was true when written and is now false, nine Fusion documents exist in
   `cad/`. The honest replacement is not "CAD exists" but the sharper statement: two mass
   estimates exist, they disagree by 54 %, and neither is FEA-verified (P5, P8).
2. **The paper claims an "ESPA-Grande-class envelope and mass allocation"** (abstract-level
   requirement, the Fig. 2 caption, and again in the accommodation section). The CAD closed
   envelope is 1839 mm against the ~1270 mm class limit, **P9, ~44 % over**. As written,
   the paper asserts a compatibility the geometry does not support.

Item 2 is the serious one: it is a capability claim, not a caveat, and it is the kind of
thing a reviewer with an ESPA user's guide open would catch immediately.

**Why this is not fixed yet.** Editing `paper.tex` without rebuilding the PDF would put the
source and the committed build out of step, and no TeX engine is available in the working
environment. It is also entangled with **P11**: until it is known which build is the
version of record, it is not clear whether this is a camera-ready edit or a corrigendum.
Resolve P11 first, then fix both items in one pass and rebuild.

### P13. The committed STEP set was mixed-generation, with two stubs: RESOLVED 2026-07-28
Found while importing `EMOCD_figs.zip`. The nine files in `cad/step/` matched no single CAD
generation, and two of them were single solids:

| Document | Was committed | Gen1 | Gen3 |
|---|---|---|---|
| Stator | **1 body** | 324 | 162 conductors |
| Interface_ESPA | **1 body** | 6 | 6 + bolt holes |
| Sled | 12 | 5 | 16 |
| Payload_3U | 5 | 5 | 1 |
| Track | 6 | 8 | 4 |
| Assembly | 225 | 43 | 227 |

The stator export therefore contained no winding at all, while `cad/README.md` claimed
"STEP exports of every document" and the paper's §IV-B rests on a winding-resolved model.
Anyone opening the committed stator to check the conductor layout would have found a block.

**Resolved** by replacing the set with `cad/step/gen1|gen2|gen3/`, the three audited
generations. Body counts measured on import with `grep -c MANIFOLD_SOLID_BREP`, not copied
from the source changelog.

### P14. Gen3 CAD defects not previously tracked: NEW 2026-07-28
From the Gen3 audit in `cad/CHANGELOG_CAD.md`, verified against the exports where possible.
None of these were in this file before.

| ID | Defect | Consequence |
|---|---|---|
| G3-D1 | Cassette height **640 mm** in Gen2 and Gen3 against `parameters.json` `magazine.cassette_height_z = 690` | 50 mm short. Either the CAD or the parameter is wrong; `parameters.json` wins by rule, so the CAD needs correcting |
| G3-D2 | Track is longerons and launch locks only, **no roller channels, guide flanges, or cross-tie outriggers**, all of which `parameters.json` specifies | The 205 mm overall track width exists only as a parameter. The rollers on the sled have nothing modelled to run in |
| G3-D4 | **Stator layer count still open.** Gen1 built two layers (324 conductors), Gen2 and Gen3 one (162) | `parameters.json` flags the decision open. Roughly x2 force for the same sheet current against x2 copper mass, never computed. This sits upstream of Kt and therefore of the headline velocity |
| G3-D5 | Halbach arrays **not re-centred** after the chassis grew 360 to 488 mm | `sled.halbach_array_x_start = 230 mm` is inherited from the shorter chassis. Array position relative to the winding is what Kt depends on |
| G3-D6 | **No payload-on-sled rigid joint** in any generation | `parameters.json` `documents.EMOCD_Assembly` specifies one. Without it the assembly cannot express the payload riding the sled, which is the thing being modelled |

| G3-D12 | **Assembly geometry extends 156 mm aft of the recorded envelope.** `EMOCD_Assembly_Gen3.step` spans x = −188 to 1810 mm; `parameters.json` records the installed envelope as −32 to 1807 mm | Either the assembly parks the sled further aft than the envelope assumed, or the envelope was measured without it. Found on 2026-07-28 while meshing the assembly for `cad/stl/`. It makes P9 worse, not better: 1998 mm against the ~1270 mm ESPA Grande class limit is ~57 % over rather than ~44 %. Measure which component owns the −188 mm face before changing either number |

**Resolved and recorded:** ESPA bolt holes (24x M9 on Ø400 mm BCD) were absent in Gen1 and
Gen2 and are modelled in Gen3, G1-D5 closed.

**Two discrepancies between `cad/CHANGELOG_CAD.md` and its own exports**, found on import
and left in place there with a note rather than edited:

- **The Gen3 brake-placement fix is not in the exports.** G2-D4 says the Gen2 brake sat at
  the local origin and Gen3 moved it to x = 1530 mm. `EMOCD_Brake_Gen2.step` and
  `EMOCD_Brake_Gen3.step` are geometrically identical, 3 bodies each, 79 points each,
  differing only in file name and time stamp, and **both** already place the brake at
  1530-1740 mm. The fix may have been applied to the Fusion document before the Gen2 export
  was taken; either way the export does not show the defect it is said to have.
- Body counts: `EMOCD_Payload_3U_Gen1.step` measures 5 solids where the inventory says 1,
  and `EMOCD_Sled_Gen1b.step` measures 11 where it says ~16.

The sled fix **is** verifiable: Gen2 chassis half-length measures 180 mm (360 mm plate),
Gen3 measures 244 mm (488 mm plate), so G2-D1 is genuinely closed.

### P15. The Gen3 sled as drawn is 9.45 kg, above BOTH existing estimates: RESOLVED 2026-07-29
> **RESOLVED by adoption.** 9.445 kg is now the operating point across `analysis/`, the
> paper and the figures. `mass_properties.py` keeps the parametric breakdown for the record
> and carries the 4.59 kg difference as an explicit reconciliation line, so system dry mass
> (76.9 kg, up from 72.3) no longer understates.

Original item follows for the audit trail.

Measured on 2026-07-28 from `cad/step/gen3/EMOCD_Sled_Gen3.step`: exact solid volumes from
the OpenCASCADE kernel, times material densities (NdFeB 7500 kg/m3 is this repo's own value,
from `sizing.py`).

| Estimate | Sled mass | Exit velocity |
|---|---|---|
| `mass_properties.py` parametric | 4.86 kg | 20.37 m/s |
| P5's CAD figure | 7.50 kg | 17.87 m/s |
| **Gen3 geometry, CAD solid-volume result** | **9.445 kg** | **16.53 m/s** at 10.7 g, 19.0 % efficiency |

The method reproduces P8 exactly when fed 7.50 kg, it returns 17.87 m/s against P8's stated
17.88, so the discrepancy is in the mass, not the method. Dominated by two chassis plates
(3.63 kg of titanium) and the magnet arrays (3.67 kg of NdFeB).

**What it does not settle.** This is geometry times density, not the structural FEA that A4
specifies. The plates are drawn solid with no lightening pockets, and a real design would
pocket them; the stiffness constraint (airgap held to ±0.05 mm) is still unevaluated. But
A4's pre-declared rule already says a mass at or above 6.80 kg makes 17.88 m/s the headline,
and this is well past that. **Whichever way the FEA goes, the 20.37 m/s headline is not
supported by the geometry that currently exists.**

Do not edit `analysis/*.py` on the strength of this. Run A4, then propagate once.

### P16. The lifetime-multiplier INVARIANCE claim is falsified: HIGH, NEW 2026-07-28
GMAT R2022a, run headless against the bands declared in `validation/A5_astro_orekit.md`
before the run:

| Solar activity | GMAT multiplier | vs x1.80 | Band ±5 % |
|---|---|---|---|
| High (F10.7 250) | 1.7302 | −3.88 % | pass |
| Mean (F10.7 150) | 1.7750 | −1.39 % | pass |
| **Low (F10.7 70)** | **2.0739** | **+15.21 %** | **FAIL** |

Spread across the three: **18.48 %** against a ≤5 % band.

**The mechanism, and it is not subtle.** `analysis/astro.py` represents solar activity as a
uniform multiplicative scale on density (`rho(h, scale)`). Sweeping that scale across a
factor of **forty** moves the multiplier from 1.7992 to 1.7968, 0.1 %. A uniform density
factor divides both lifetimes by the same number, so **the ratio is preserved by
construction**. The sweep that the paper cites as demonstrating invariance cannot, in
principle, do so.

MSIS varies the *shape* of the density-altitude profile with F10.7, not only its magnitude.
The boosted orbit's apogee sits ~37 km above the baseline's, the two sample the profile
differently, and the ratio moves. Corroboration from the same runs: the absolute-lifetime
error changes **sign** across the range, GMAT is 2.5x longer at low activity, 9 % shorter
at mean, 23 % shorter at high. An error that changes sign is a wrong shape, not a
miscalibration.

**What survives:** x1.80 as a point value at mean and high activity, checked independently
and comfortably inside band. **What does not:** invariance.

Reproduce the sweep in six lines, no edit to any script:

```python
from analysis.astro import lifetime, boosted_elements, RE
a0 = RE + 450e3
ab, eb = boosted_elements(450e3, 20.37)
for s in (0.25, 0.5, 1.0, 2.5, 5.0, 10.0):
    print(s, lifetime(ab, eb, scale=s) / lifetime(a0, 0.0, scale=s))
```

**Where the claim appears:**

| Location | Text | Status |
|---|---|---|
| `paper/paper.tex` **abstract** | "a ratio shown invariant across ballistic coefficient and a fivefold solar-activity density range" | corrected 2026-07-29, multiplier now quoted at a stated activity level, no invariance claimed |
| `paper/paper.tex` Sec. V-B | "invariant to two decimal places" | corrected 2026-07-29, carries the GMAT three-level result and the mechanism |
| `paper/paper.tex` sensitivity section | "a multiplier invariant across a fivefold density range" | corrected 2026-07-29 |
| `paper/paper.tex` **Limitations** | "the demonstrated invariance of the ratio is the defensible result", the paper leaned on this specific claim | corrected 2026-07-29, no longer offered as the defensible result |
| `README.md`, `wiki/Home.md` headline tables | "x1.80, invariant across BC and solar activity" | corrected 2026-07-28 to "x1.80 at mean activity, invariance falsified, see P16" |
| `docs/RESULTS.md` A5 section and status bar | "GMAT: x1.73 vs x1.80, within band" | corrected 2026-07-28, three-level table, per-activity chart, 40x-sweep chart, status FAIL |
| `docs/index.html` (Pages site) | headline row and GMAT section | corrected 2026-07-28 |
| `docs/VALIDATION_REPORT.md` §2 | "2.55 % spread, inside the ≤5 % band" | corrected 2026-07-28, retraction stated in place |
| `docs/INVENTORY.md` A32 | "Solar-activity UQ, x1.80 invariance" | flagged against P16 |
| `CHANGELOG.md` VAL2-02 | "Invariance spread 2.55 %, inside ≤5 %" | marked SUPERSEDED, text left intact as audit record |
| `paper/figures/F11_uq.png` **caption** | "absolute lifetimes vary fivefold; the x1.8 multiplier does not", a fifth location, missed when this list was written | corrected 2026-07-29, figure now plots `astro.py` against GMAT side by side |

**All documented locations are now corrected.** What is *not* closed:

1. **The BC half has still never been tested against a real atmosphere.** It is proven a
   tautology in `astro.py`, and the paper no longer claims it, but nobody has run GMAT at
   BC 40 and 90 to find out what the true BC dependence is. Until that happens the honest
   position is "unknown", not "invariant".
2. **The GMAT numbers themselves are now stale**, every run was at 20.37 m/s (P19).
3. **The committed PDF predates the correction** (`paper/README.md`).

This item stays open on (1).

**Ballistic-coefficient invariance is not "suspect", it is the identical tautology, proved
2026-07-29.** The abstract's sentence has two halves: invariant across *ballistic
coefficient* **and** across a *fivefold solar-activity density range*. Both rest on the same
construction. In `lifetime()` the drag term is

```python
ft = -0.5 * rho(h, scale) * v ** 2 / BC
```

`scale` and `1/BC` are the **same multiplicative slot**. Scaling one is mathematically
indistinguishable from scaling the other, so a BC sweep is a density sweep wearing a
different label. The reciprocal test confirms it exactly:

| Configuration | Multiplier |
|---|---|
| BC = 61, scale = 2.0 | 1.7987 |
| BC = 30.5, scale = 1.0 | **1.7987** |
| BC = 122, scale = 1.0 | 1.7991 |
| BC = 61, scale = 0.5 | **1.7991** |

And the plain sweep across a 5x BC range, 30 to 150 kg/m²: 1.7983 to 1.7992, spread
**0.05 %**.

So the position is worse than "one half falsified, one half untested". **Neither half of the
claim was ever tested by a method capable of falsifying it**, and the half that was
independently checked failed. Closing the BC half needs the same medicine as the solar half,
GMAT runs at BC 40 and 90, because MSIS's response to ballistic coefficient is not a uniform
rescale, for the same profile-shape reason found above.

**Do not edit `analysis/astro.py`.** Its arithmetic is not wrong; its atmosphere
parameterisation cannot express the effect being claimed. The fix is either a variable-shape
atmosphere in the script or dropping the invariance claim and keeping the point value,
that is a judgement, not a patch. Paper edits batch with P11/P12.

### P17. The inter-array attraction feeding the A4 FEA is 37 % high: **RESOLVED 2026-07-31 by A12**
> **Closed by [`validation/A12_inter_array_force.md`](validation/A12_inter_array_force.md), five
> of five declared bands.** A second numerical method — a Maxwell stress tensor integrated over
> the mid-gap plane, sharing only the block model of the magnets — gives **2627.6 N** against
> magpylib's **2686.6 N**, 2.2 % apart. `sizing.py` adopted 2686.6 N under an adoption rule
> declared before the run: attraction 3.68 → **2.69 kN**, plate stress 33 → **24 MPa**, margin
> 20.2 → **28.1**. A4 is not re-run; it was loaded 37 % heavy, so it was conservative and its
> verdict stands.
>
> **The number below was right and the mechanism below is wrong**, which is why the entry is
> corrected in place rather than deleted. See the correction at the end.
`analysis/sizing.py::inter_array_attraction()` computes the force between the two opposed
Halbach faces from a flat-plate Maxwell-stress formula, a uniform pressure
`B_face**2 / (2*mu0)` at a mean face field of 0.55 T over the 340 x 90 mm footprint,
giving **3672 N**. That number was the applied load in the CalculiX A4 structural run
(`validation/results/A4_sled_structural.json`), and it had never been checked against
anything.

`magpylib.getFT()` meshes each magnet block and integrates the field gradient in three
dimensions. Driven by the repo's own array geometry (`build_field()`), so the two methods
cannot disagree about the magnets themselves:

| Mesh per block | Force |
|---|---|
| (2,2,2) | 2909.4 N |
| (4,4,4) | 2773.0 N |
| (6,6,6) | 2720.8 N |
| (8,8,8) | 2701.6 N |
| (10,10,10) | 2693.3 N |
| (12,12,12) | 2689.0 N |
| **(14,14,14)** | **2686.6 N** |

Converged (successive deltas halve (-8.3, -4.3, -2.5 N)) and insensitive to the
finite-difference step across four orders of magnitude (1e-5 to 1e-8, identical to 0.1 N).
**The analytic formula is high by 36.7 %.**

~~**The mechanism is understood, which is why this is a defect and not a disagreement.**
Maxwell stress needs the mean of `B**2`; the analytic form uses the square of the mean `B`;
and `mean(B**2) >= mean(B)**2` for any non-uniform field, by Jensen. A Halbach face field is
strongly non-uniform along the wavelength, so the analytic form must overestimate. It does.~~

> **CORRECTED 2026-07-31 by A12. The inequality is right and the conclusion drawn from it is
> the wrong way round.** If `mean(B^2) >= mean(B)^2`, a one-point form evaluated at the *true*
> mean field **under**estimates. Jensen cannot be why the analytic value is high.
>
> A12 decomposed it against M2's own field statistics on the stress plane:
>
> | | Force | |
> |---|---|---|
> | Analytic, `B_face = 0.550 T` assumed | 3683 N | as published |
> | Same one-point form at the **actual** mean, 0.4127 T | 2073 N | **x1.776 from the assumed field** |
> | Full integral, `mean(B_y^2)` | 2628 N | **x1.267 back the other way, from Jensen** |
>
> Net x1.402 against an observed x1.402. **The cause is the input, not the formula:** 0.55 T is
> not the mean normal field on the plane where the stress acts. The flat-plate form's own Jensen
> error is 27 % and in the *safe* direction; it was fed a field 0.33x too high, which swamps it.
>
> **A right number with a wrong explanation attached is worse than an open question**, because
> it survives review and then misleads whoever picks it up next. That is why this is struck
> through and left visible rather than quietly rewritten.

**What this does and does not damage.** The real force is *lower*, so A4's structural
results are conservative, not wrong: 0.0194 mm airgap closure and 33.7 MPa were computed
against a load 37 % heavier than the field model supports, and all three bands still passed.
No A4 conclusion reverses. What is damaged is the claim that A4's inputs were checked, they
were not, and this is the first time anyone looked.

**Reproduce:** `python3 validation/magpylib/check_inter_array_force.py` (no new dependency;
magpylib 5.2.3 is already in `requirements.txt`).

**Procedural note, stated rather than hidden.** This was computed *before* an acceptance band
was declared for it, which inverts this project's own rule. It is therefore logged as a
discrepancy, not as a validated result. Proper closure needs a run sheet with a band declared
in advance, and a decision about whether `sizing.py` adopts a corrected formula, which would
move `plate_stress_MPa`, ~~the retention-gate sizing,~~ and the A4 load together. **Do not edit
`sizing.py` on the strength of this entry.**

> **Done 2026-07-31.** A12 declared the bands and the adoption rule first, then ran. The
> retention gate is struck above because it does not depend on this: `retention_gate()` is sized
> from a 24 kg ascent stack at 25 g. This entry was wrong about its own blast radius.

### P18. Four physical effects are absent from the model, not merely unvalidated: MEDIUM, NEW 2026-07-29
Distinct from the E-items, which record analyses not yet run. These are terms that no script
contains, found by reading `sizing.py` and `motor_model.py` rather than the prose. Each is
carried as an E-item below (E19-E22); this entry exists so they are visible from the P-list,
because "the model does not contain this term" is a different class of gap from "this
analysis has not been run".

### Advanced or resolved by the CAD build (not full closures)
- **Launch restraint now exists as geometry.** The breech launch-lock blocks are modelled
  (`cad/parameters.json` `track`: `launch_lock` at x = 30-50 mm, 2 off). This advances
  **E10** (previously "concept-level"), the lock is drawn, though still not analysed.
- **Payload interface now models CDS corner rails** (see P6), giving the rail contact
  faces the interface-control drawing needs.

---

### P19. Every validation run predates the operating point they validate: HIGH, NEW 2026-07-29
Adopting the CAD-derived 9.445 kg sled moved the rated velocity from 20.37 to 16.537 m/s. The
three analyses that have actually been run were all executed at the **old** point, so none of
them currently validates the design as it stands:

| Analysis | Run at | Still valid? |
|---|---|---|
| **A5** GMAT lifetime | dv = 20.37 m/s | **No.** Both baseline and boosted orbits change; the multiplier the scripts now give is x1.62, not x1.80. The *falsification* of the invariance claim (P16) survives, because that is about the shape of the model and not the velocity, but the numbers do not. |
| **A8** ngspice pulse chain | F = 1413.4 N, m = 8.86 kg, 2630 J | **Re-run 2026-07-30 as A8-R** against fresh bands, at 16.537 m/s. Five of six met; the closure row failed and produced P24. This half of the item is closed. |
| **A4** CalculiX chassis | 3672 N Maxwell attraction | **Yes, structurally.** The load is magnetostatic and does not depend on sled mass or velocity. **37 % heavy**, corrected to 2686.6 N by A12 — so A4 is conservative and is deliberately not re-run. |

**What this costs.** The validation table on the front pages says four of nine analyses have
run (A1 added 2026-07-29, and A1 alone is at the current operating point). Strictly, three have run *against a superseded design*. That is not the same claim, and
the difference is exactly the kind a reviewer notices.

**A8 is done.** A5 remains, and is days of wall time for the low-activity leg.
Neither should be re-run until the sled mass is settled, or the same staleness recurs; that
argues for closing the rib-stiffened-chassis question (P5, E2) **first**.

**Do not quietly restate the old results as if they still applied.** Every place the repo
quotes A5 or A8 numbers now needs the velocity they were obtained at stated alongside.

### P20. The A1 run sheet's array-surface reference is mis-specified: LOW, NEW 2026-07-29
A1 ran and missed two of its seven declared bands. **One of the two is a defect in the run
sheet, not in the model.**

`validation/A1_field_femm.md` declares the array-surface band against
`analytic_B0_surface_T` = 0.7714 T. That is the fundamental amplitude of a **single** array's
ideal Halbach wave at its own surface. But any measurement at that plane in a **double-sided**
machine inevitably includes the opposing array, whose contribution there is
`B0·exp(-k·GAP)` = 0.160 T. The correct double-sided reference is **0.9317 T**.

The FEM's fundamental at that plane is **0.9312 T, a ratio of 0.9994 against the correct
value.** Measured as a raw peak it reads 1.4641 T, because the plane sits on the magnet face
where block-corner harmonics dominate and the field is formally singular at the corners; a raw
peak there is mesh-dependent and is not the same quantity as a fundamental amplitude either.

**So the row failed as declared, and the model is right.** Both statements are true and both
are recorded. The band is **not** widened, `validation/A1_field_femm.md` is left exactly as
written on 2026-07-27, because a run sheet edited after seeing results is worth nothing. The
correction belongs in the *next* run sheet.

**Fix:** when A2 (3-D) is specified, declare the array-surface band against the double-sided
value and against the **fundamental**, not a raw peak. Two references need naming, not one.

### P21. Stray field at 50 mm: 2-D cannot test the far field: LOW, NEW 2026-07-29

> **QUANTIFIED 2026-08-05 by `analysis/far_field_sensitivity.py`.** P3's diagnosis was right and
> the size of it was not known. Sweeping `build_field(n_wave)` from 3 to 15 wavelengths against a
> converged reference:
>
> | Station | Deviation at the default n=7 (336 mm) | Converged |
> |---|---:|---:|
> | 10 mm | **0.64 %** | 22.688 mT |
> | 20 mm | 4.36 % | 4.290 mT |
> | 50 mm | **374 %** | 0.104 mT |
>
> **The 10 mm value is converged and the 50 mm value is not remotely.** At n=7 it is 0.49 mT
> against a converged 0.104, and it is still 16 % out at n=13. The paper's 1.0 mT corresponds to
> an array shorter than the CAD's 340 mm. **No 50 mm stray figure in this project should be
> cited**, including the 0.4 mT in `field_verification.json`, until the array length is set to
> the CAD value and the model converged.
>
> This needs no mesh: magpylib's Cuboid is an exact analytic solution for a uniformly magnetised
> block, so the field is already three-dimensional. What was missing was the convergence check.
The second A1 band miss. FEM gives 0.93 mT against a 0.4 mT reference, ratio **2.32** against
a factor-2 band.

**Cause identified, and it is geometric.** The FEM is 2-D: the array is infinitely long out of
plane. The real array is **90 mm deep**. At 10 and 20 mm behind the back face the observation
distance is small against that depth and the two agree (ratios 1.16 and 1.14, both inside
band). At 50 mm the distance is comparable to the depth, a finite source falls off faster than
an infinite one, and the 2-D model necessarily overestimates.

This is **converged, not noise**: the value sits at 0.93 mT across box sizes 0.5-0.8 m and
across mesh refinements from 32 k to 141 k elements.

**Consequence:** a 2-D method cannot validate this row, by construction. `A1_field_femm.md`
already says A1 "does not close 3-D end effects", this is that limitation showing up in the
one row most sensitive to it. The magpylib reference, which models finite 90 mm blocks
exactly, is the more trustworthy number here and the FEM is not evidence against it.

**Do not** change `verify_field.py`. The row needs A2, a 3-D solve.

### P22. The novelty claim was wrong, and its replacement rests on abstracts: HIGH, NEW 2026-07-30
A literature check found **published work on this exact concept that the paper did not cite.**
Full record in [`docs/PRIOR_ART.md`](docs/PRIOR_ART.md).

**What was wrong.** §I asserted *"no published deployment system operates in the tens of m/s."*
Feng, Yang & Wu (*Int. J. Aerospace Eng.* 2025, art. 3000765) analyse an on-orbit multi-stage
induction coilgun regulating a 20 kg CubeSat to **321.56 m/s**, with a reachable-domain analysis
serving the same purpose as this paper's lifetime and phasing argument. It was published
**2025-11-12, eight months before this repository went public.** The sentence was false as written.

**What it was changed to.** The regime is unserved *by flown hardware*, which is what the
comparator table always actually showed. The contribution is re-scoped to the narrower and more
defensible claim: a **programmable velocity delivered to an unmodified satellite inside its own
qualification envelope.** Both qualifiers carry weight, and against Feng they carry more than they
did against a spring:

| | Why it holds |
|---|---|
| Unmodified satellite | An induction coilgun accelerates a *conductive armature*, attached to the customer satellite, or a sabot needing its own separation. ADR-006 forbids the first |
| Inside the g-limit | 321.56 m/s at 10.7 g requires a **493 m track**; over 1.5 m it is **3515 g**. Not a secondary payload |

The g-limit argument is not new (ADR-003 made it in mid-2025) but it was an assertion and is now
arithmetic against a published number.

**The declared band, and what happened to it.** Before the full texts were obtained, this was
written down: *if Feng et al. report closed-loop per-satellite velocity regulation at dispersion
comparable to this design's 0.027 m/s 3σ, "programmable" stops being a differentiator; if they
report a track length making 321 m/s survivable for a standard CubeSat, §I needs rewriting rather
than adjusting.*

**All five papers were then supplied and read on 2026-07-30. Neither trigger fired, and three of
this entry's own conclusions turned out to be wrong.** Corrections in
[`docs/PRIOR_ART.md`](docs/PRIOR_ART.md); the material ones:

| Claimed from the abstract | After reading |
|---|---|
| "321.56 m/s at 10.7 g would need a 493 m track", a hypothetical | Their **actual** barrel is 3.9 m to **1352 g** mean, ~3060 g peak from their own >600 kN. The fact is far more decisive than the hypothesis |
| ADR-003's unsourced "1-2 % coilgun efficiency", removed *pending Einat* | **False.** Feng reports **14.9-19.9 %**, comparable to this design's own 20 %. Einat cannot settle it, a **2.5 g** projectile. Argument withdrawn as wrong, not deferred |
| *Aerospace* 12(6) 466 "has experimental verification" | True but narrower: a **32.8 mm/s transport mechanism**, not an ejection |

**Feng quotes no dispersion figure at all**, and controls velocity by charging-voltage selection
(10 to 16 kV to 230 to 321.56 m/s). So the dispersion differentiator survives, but as a claim about
*absent evidence*, not about impossibility, and it is written that way now. Feng is also
**simulation-only**, so on maturity this project and theirs are peers rather than this one being
behind.

**Why it stays open.** The claim corrections have landed, but two things are unfinished:

1. **The reachable-domain method should probably be adopted.** Feng's 3-D reachable-set envelope
   answers "which orbits does one shot make available" directly, where this project reports a scalar
   lifetime multiplier. That is a better astrodynamic product and it is the strongest thing to take
   from this literature. Not yet done, Phase II candidate.
2. **E24**, below: Xu et al. model attitude disturbance from the transfer mechanism itself. This
   project has nothing on disturbance from magazine indexing between shots.

**The maturity gap is real and remains.** The Harbin group built and measured a prototype. This
project has measured nothing. `docs/BENCHTOP_TESTS.md` already specified the answer as **B-1** and
**B-2**; what was added on 2026-07-30 is that their bands are now **derived** from an error budget
rather than chosen, by `validation/bench/bench_predict.py`. See E4.

### P23. The stroke time is stale in six places, and A8's band was set at the old one: MEDIUM, NEW 2026-07-30
Found while building the shot animation, which draws its time axis from `motor_model.shot()`
and came out at **157.3 ms** against the **127.7 ms** printed everywhere else.

127.7 ms is the superseded figure. Under constant acceleration the stroke time is `2s/v`:

| Operating point | 2s/v over the 1.30 m accel zone |
|---|---|
| 20.370 m/s, the pre-P15 point | 127.6 ms |
| 16.537 m/s, current | 157.2 ms |

So it belongs to the 4.86 kg parametric sled and survived the P8/P15 propagation in six
places: `README.md` twice, this file's E23 entry, `validation/A8_pulse_spice.md` twice, the
`CHANGELOG` record of A8's bands, and `docs/VALIDATION_REPORT.md`.

**The part that matters is not the typo.** `validation/A8_pulse_spice.md` declared a band of
**127.7 ms +/-10 %**, so 114.9 to 140.5 ms, and `VALIDATION_REPORT.md` records A8 passing it at
127.66 ms. At the current operating point the value is 157.3 ms, which is **23 % above the band
centre and outside the band entirely**. A8's recorded pass is a pass against a superseded
target.

This is the concrete instance of what P19 says in general. It is not a new failure: A8 ran
correctly against the operating point that existed when it ran. But "A8 passed" cannot be
quoted without saying which operating point it passed at, and until it is re-run the row in
`VALIDATION_REPORT.md` overstates what is known.

**Done:** the four prose occurrences corrected to 157.3 ms.

**Closed 2026-07-30 by A8-R.** The original band and its recorded result are left exactly as they
were, marked as belonging to the superseded point, because rewriting a declared band after the
fact to fit a new number is the one move that would make the whole validation record worthless.
Fresh bands were written and committed before the deck was touched, and the re-run passes the
pulse-duration row at 157.26 ms against 157.3. It failed a different row, which is P24.

### P24. No script carries a bank ESR, and the placeholder standing in for it is a factor of two high: HIGH, NEW 2026-07-30
Found by A8-R, the re-run of the pulse-power simulation at the current operating point
(`validation/A8_pulse_spice.md`). Five of six bands passed. Energy closure failed at **97.0 %**
against a declared 98-102 %.

The simulated draw exceeds the analytic accounting by **86.6 J**. That gap is bank ESR
dissipation, which the circuit deck models and the analytic ledger has no term for:

| | |
|---|---|
| I^2 dt over the shot, integrated by ngspice | 7126.2 A^2 s |
| Bank ESR, per `sizing.py` | 0.012 ohm |
| Product | **85.5 J**, against an 86.6 J gap, agreeing to 98.7 % |

**The ledger is internally consistent and still understates the bank.** `energy_closure()` has no
ESR term, and the `E_DRAWN = 2795.6 J` it closes against comes from `motor_model.py`, which has no
ESR either. Both sides of the equation omit the same term, so the closure reads 100.0 % while the
real draw is about **2881 J**, 3 % higher.

**What moves if the term is carried:**

1. **`thermal_campaign()` carries `Q_esr = 160 J`** as a literal default. Against 85.5 J that is
   1.9x high, and the twelve-shot campaign falls from 28.9 to 28.0 kJ. It was flagged as unsourced
   during the P2 review and has had no second number against it until now.
2. **The per-shot energy headline, 2.80 kJ**, is the analytic draw and appears on the front pages.
   It becomes 2.88 kJ, and electrical-to-payload efficiency falls from 19.6 to about 19.0 %.
3. **Quoted bank sag, 5.19 %**, is the charge depletion with no ESR in the loop. The true figure is
   the 5.35 % A8-R measured.

### Retracted, same day it was written: the claim that the bank goes undersized

This entry first stated that `capacitor_sizing()` at the true draw wants **6.18 F** against the
6.0 F selected, and that the bank was therefore chosen against a draw omitting a loss it causes.
**That is wrong, and the error is in how it was computed.** The 6.18 F came from raising the
energy to 2881 J while holding `SAG_FRAC` at 5.19 %. The two are not independent: the ESR
dissipation is drawn out of the same capacitor, so a higher draw *is* the higher sag. Evaluated
consistently, at 2881 J and 5.35 %,

```
C = 2E / (V0^2 - V1^2) = 2(2881) / (96^2 - 90.864^2) = 6.00 F
```

against 6.0 F selected. **The bank is correctly sized and always was.** The sizing function is not
implicated, and the propagation below is a constant change rather than a design decision.

The mechanism is worth naming because it is a general trap in this repository: `capacitor_sizing()`
takes `E` and `sag_frac` as separate arguments, and its own docstring warns that `sag_frac` is the
droop the shot integration reaches rather than a target. Feeding it a new energy with a stale sag
violates that, and the function has no way to notice.

### Propagated 2026-07-30, in the same pass that wrote this entry

`motor_model.py` gained `R_ESR = 0.012` and now solves `R I^2 - Vc I + P = 0` for the current the
load draws at the bank **terminal** rather than at the capacitor, integrating `Vc*I` out of the
bank and `I^2 R` into a new `Q_esr` output. `sizing.py` follows: `E_DRAWN` 2795.6 to 2881.2 J,
`SAG_FRAC` 5.19 to 5.35 %, `energy_closure()` carries the term on both sides, and
`thermal_campaign()`'s literal 160 J becomes the computed 85.6 J.

Eleven result fields moved, all electrical or thermal. **Exit velocity, acceleration, stroke time,
dispersion, the payload family, mass and cost are unchanged**, which is the expected signature of
an electrical-only correction and was checked rather than assumed.

The correction also closed a disagreement nobody had attributed. A8 and A8-R both recorded peak
current about 5 % above the analytic model and put it down to the integrator. It was the ESR:
corrected, the model gives 346.77 A against ngspice's 346.8.

**This is a simulation result, not a measurement.** It gives a placeholder its first independent
number, which is what E17 asked for, and it is still one model checking another.

> **Superseded in part, 2026-07-30 by A10.** Everything above is arithmetically correct and
> still describes what the model does. What it assumed is not: **12 mohm is not purchasable at
> this bank capacitance**, and at a realistic value the shot does not close at all. The 86 J
> figure is therefore the ESR loss of a bank nobody can build. See **P26**.

### P25. A retracted claim stayed live in the paper, the wiki and two docs for a day: MEDIUM, NEW 2026-07-30
P22 withdrew ADR-003's assertion that coilgun efficiency is "1-2 % in the literature", after
Feng et al. were found reporting **14.9-19.9 %** for a multi-stage on-orbit CubeSat launcher.
The withdrawal was recorded in `docs/adr/003`, `docs/PRIOR_ART.md`, `docs/RELATED_WORK.md` and
the changelog.

**It was not propagated to the places that actually assert it.** Four survived:

| Where | What it said |
|---|---|
| `paper/paper.tex` Table I | *Electrical to payload efficiency: coilgun 1-2 %, this work 19 %* |
| `paper/paper.tex` §II and §III | the same figure, once as background and once as a listed cost of the coilgun |
| `wiki/Home.md` | "1-2 % single-stage efficiency" in the locked-decisions list |
| `docs/PROJECT_NOTES.md` | the same, in the locked-decisions list |

**Table I is the one that matters.** It is the architecture trade, and that row claimed an
order-of-magnitude efficiency advantage that the prior art says does not exist. Corrected, the
row reads 14.9-19.9 % against 19 %, which discriminates not at all. The decision survives on the
rows that always carried it: no armature on the customer satellite, closed-loop velocity control,
and an abort path to 45 % of stroke.

**Found by reading the wiki page after publishing it**, not by any check. That is the finding.
The retraction was logged in four places and propagated to none, and nothing in the repository
notices when a ledger entry and an artifact disagree, because the mechanical guards
(`make_baseline.py --check`, `_check_operating_point()`, `check_links.py`) all compare artifacts
to *scripts*. A claim withdrawn in prose has no such guard.

**Half the general case is now fixed**, 2026-07-30. The same blindness had already shipped a
stale PDF: `paper.tex` was corrected twice and the published PDF went on printing the retracted
figure for five hours until it was found by hand.
[`tools/check_artifacts.py`](tools/check_artifacts.py) closes that half by comparing each built
artifact to the sources it was built from, using the commit each was last changed in rather than
file mtimes, which git does not preserve and which a fresh clone destroys. Verified against the
actual failure: at commit `c406da4` it reports the PDF **5.1 hours behind** its own source.

**The other half stays open and is the harder one.** A claim withdrawn in prose still has no
guard. Catching that needs a list of load-bearing claims and where each is asserted, which is
`docs/PROVENANCE.md`'s job and would roughly double it. What is now true is that the *mechanical*
half of this defect cannot recur silently.

### P26. The supercapacitor bank cannot source the shot: HIGH, NEW 2026-07-30
P24 recorded that the 12 mohm bank ESR had no source. Looking for one found that the value is
not merely unsourced, it is **not attainable from the cells the design specifies**, and that the
shot does not close without it. Full run: [`validation/A10_bank_esr.md`](validation/A10_bank_esr.md).

**The physics.** For an EDLC, ESR times capacitance is roughly constant within a cell
technology: both are set by the same electrode area and separator. Two Eaton 3.0 V cells thirty
times apart bracket it, and series stacking preserves the product because R scales with N and C
with 1/N.

| Cell | C | ESR | ESR x C |
|---|---|---|---|
| TV1860-3R0107-R | 100 F | 11 mohm | 1.10 s |
| XL60-3R0308T-R | 3000 F | 0.23 mohm | 0.69 s |
| **This bank, as modelled** | **5.94 F** | **12 mohm** | **0.071 s** |

The bank as modelled is an order of magnitude better than either commercial cell. At a realistic
product it is **116 to 185 mohm**.

**The consequence is not a worse efficiency. It is no shot at all.** A source of EMF V behind
series resistance R cannot deliver more than `V^2/4R` into any load. At the rated point the
shot needs 30.0 kW at peak velocity. A10 swept the integrator and found the design completes up
to **65 mohm and fails from 70**, against the 116 to 185 mohm the cells actually give.

| | |
|---|---|
| Hard ceiling on bank ESR | **65 mohm** |
| A single string of 32 x 190 F cells | **116 to 185 mohm** |
| Margin | **none: short by 1.8x to 2.8x** |

**Nothing else in the design is implicated.** Exit velocity, stroke time and dispersion do not
move anywhere in the sweep, because the commanded force is constant and the mechanical
integration never sees the bank until the bank fails to source it. K_t, the magnets, the
winding and the control loop are untouched. This is a pulse-power defect and it is contained
there.

**Not propagated, and that is deliberate.** The baseline still reads 16.537 m/s at 2.88 kJ,
which assumes a 12 mohm bank that cannot be bought. `docs/BASELINE.md`'s change-control rule
admits error correction; what is needed here is a **sizing decision**, and taking one on the
strength of two datasheet points would be exactly the reasoning this repository logs defects
about. Options costed as **PII-7**.

**The gap that let this through, and it is on the record already.**
[`docs/LITERATURE.md`](docs/LITERATURE.md) has 136 entries across nine clusters, and its
pulsed-power-and-capacitors cluster has **two**. The file names that cluster as the sample's
blind spot in its own words. The one area nobody filled is the one that turned out to carry a
defect big enough to stop the machine.

**What is still soft.** Both cell figures come from distributor listings of manufacturer data,
not from the manufacturer PDFs, which are unreachable from the environment this was written in.
A third mid-range point was not obtained. If space-qualified cells behave differently the
numbers move, though the ceiling at 65 mohm does not: that is set by this design's own power
demand and is independent of any datasheet.

### P27. A numerical guard hid the failure it was written next to: MEDIUM, NEW 2026-07-30
Found by A10 on its first run, before it found anything about the bank.

`shot()` solves `R I^2 - Vc I + P = 0` for the current drawn at the bank terminal. When the
discriminant went negative it fell back to `I = P/Vc`, the current the load would draw with no
ESR at all. That branch was added on 2026-07-30 in the same commit as the ESR term itself,
as an ordinary numerical guard.

**A negative discriminant is not a numerical edge case. It is the bank being unable to source
the demanded power**, which is precisely the condition A10 exists to detect. The fallback
converted it into a completed run with a working machine in it, at every resistance tested.

The tell was visible in the output and nearly missed: **peak current fell from 630 A at 70 mohm
to 331 A at 183 mohm.** Demanded power was fixed, so current cannot fall as resistance rises.

**Fixed:** the branch raises `BankLimitError`, naming the power demanded, the `V^2/4R` ceiling,
and the point in the stroke where it was hit. The baseline is unaffected, because at 12 mohm the
discriminant never goes negative.

**The general lesson, which is why this is a numbered defect and not a commit message.** Every
other guard in this repository fails loudly: `_check_operating_point()` exits, `make_baseline.py
--check` exits, `bench_predict.py` raises on geometry drift. This one substituted a plausible
value and continued. A guard that degrades silently is worse than no guard, because it converts
a detectable failure into a credible wrong answer.

### P28. The regen stator and the eddy fin do not both fit the arrest section: MEDIUM, NEW 2026-07-31
Opened by A11 in the act of adopting regenerative braking, and recorded rather than designed
around.

The closed envelope is 1839 mm and release is at 1500 mm, so the arrest section is **339 mm**.
A11 assumes 240 mm of it carries regenerative stator. The eddy fin as sized in `sizing.py` is
**300 mm** long (0.86 kg of 4 mm copper). **240 + 300 > 339.** Both live in the same airgap, so
they cannot overlap.

**The thermal half is not the problem.** Regeneration cuts the fin's duty from 1291 to 952 J, a
26 % reduction, and the fin's adiabatic rise falls from 4.0 to 3.0 K. A fin a third of the
length would still hold its transient.

**The mechanical half is unresolved, and it is tighter than it looks.** Eddy force is
proportional to velocity, so distance to arrest is linear in the velocity removed:
`x = (m/c)*(v0 - v1)`. At the first-order coefficient `paper/make_figures.py` uses,
`c = 670 N*s/m`, the sled needs **186 mm** to fall from 14.2 to 1.0 m/s, and only about 99 mm
would remain. Closing that means **c rising to roughly 1210 N*s/m, a factor of 1.8**, which puts
peak deceleration at **186 g against the 200 g taper cap** — inside it, with 7 % to spare, on a
cap that exists to protect the bonded magnet interfaces. That is not a comfortable margin, and
it is the reason this is a numbered defect and not a note.

**Regeneration is what makes the repartition even arguable.** Without it the sled enters the
brake at 16.5 m/s and the same 99 mm would need `c = 1440`, putting peak deceleration past the
cap outright. The 240 mm of regenerative stator pays part of its own packaging cost.

**Why this is logged instead of fixed.** The obvious fix is to shorten `fin_mass` in
`thermal_campaign()` until the numbers fit. `validation/README.md`'s conventions forbid exactly
that: *"do not hand-edit a script to match an FEA result, record the discrepancy first, decide
second."* The same applies to hand-editing one to match a packaging wish. `sizing.py` keeps the
300 mm fin and carries a comment saying it does not fit.

**What would close it.** A repartitioned arrest-section layout with the fin resized on eddy
authority rather than on heat, checked against the 200 g deceleration cap and the ring-spring
handover below 1.5 m/s. It is mechanical design, and it is the reason A11 says plainly that it
answers the electromagnetic question only.

### P29. The paper says the winding is segmented; the model charges copper for all 1.3 m: MEDIUM, NEW 2026-07-31
Found while pricing a longer track, and it is a question about the machine as built rather than
about any proposal.

`paper/paper.tex` §VII states, under redundancy: *"the winding is segmented so a shorted coil
degrades thrust rather than ending the campaign."* `motor_model.shot()` computes copper loss as
`RHO_CU * J^2 * vol_cu` with `vol_cu = ACCEL_ZONE * DEPTH * WIND_THICK * FILL`, that is, **the
whole 1.30 m winding carrying full current density for the entire 157 ms stroke**.

Those are not consistent with each other. A segmented long-stator machine energises the section
under the mover — roughly the sled's 340 mm active length — and switches segments as it passes.

**What it is worth.** Energising 340 mm rather than 1300 mm takes copper loss from **827.9 J to
about 217 J**, and electrical-to-payload efficiency from 21.2 % to roughly **24.4 %**, with no
design change whatsoever. It also drops peak current from 347 to about 296 A, which raises the
A10 bank ESR ceiling from 66 to about 79 mohm — relevant to P26, though not enough to reach a
single commercial string at 116.

**Three possibilities and this repository cannot currently distinguish them.**

1. The winding is segmented for *fault tolerance* but driven as one, in which case the model is
   right and the paper's sentence is about failure modes only. Then nothing is wrong and the
   distinction needs stating, because a reader will assume block commutation.
2. The winding is block-commutated and the model is deliberately conservative. Then the
   conservatism is real engineering judgement and **it is written down nowhere**, which is the
   same defect class as the 12 mohm ESR (E17): a value with no provenance.
3. It is simply inconsistent, and `Q_copper` is overstated by a factor of about 3.8.

**Why this is logged rather than fixed.** Changing `vol_cu` moves a baseline number, and which
way it should move depends on a design decision nobody has recorded. Guessing in either direction
would put an unsourced value into the baseline, which is exactly what P24 and E17 exist to stop.
`cad/parameters.json` `groups.stator` records conductor counts and belt geometry but says nothing
about drive segmentation, so the CAD cannot settle it either.

**What would close it.** A recorded decision on how many stator segments exist and how many are
energised at once, then `motor_model.py` computing `vol_cu` from that rather than from
`ACCEL_ZONE`, with the paper's redundancy sentence and the drive description made to agree.
Both numbers then follow from one stated fact instead of two unstated ones.

### P30. An acceptance band was set at the easier of two available comparators: MEDIUM, NEW 2026-07-31
**A defect in how a band was chosen, not in a number.** This repository has no other entry of that
kind, which is the reason to write it down.

`validation/A7_separation_chrono.md` declared its tip-off band as **≤ 5 °/s/axis**, citing the
NanoRacks NRCSD-E interface document. Three other files — E7 above, `docs/KILL_CRITERIA.md` §4 and
PII-1's entry criterion in `docs/PHASE_II.md` — carried a standing flag that this "conflicts" with
a sibling NRCSD ICD quoting 2 °/s, and that the conflict had to be resolved before the band meant
anything. PII-1, the best available velocity lever, was gated on it.

**There is no conflict. They are two different deployers and both numbers are right:**

| | Tip-off target | |
|---|---|---|
| **NRCSD**, internal, ISS airlock | **< 2 °/s/axis** | flown hundreds of times |
| **NRCSD-E**, external, Cygnus-mounted | < 5 °/s/axis | *"additional testing and analysis are being completed... to refine and verify this value"* — its own publisher |

**What that leaves is worse than the flag it replaces.** The band was set at the looser of the two
comparators, taken from the document whose publisher describes the figure as provisional, with
nothing recorded about the tighter flown number existing. Nobody chose the easy number on purpose;
it is what happens when a band cites one source and no one asks what else the source set contains.
**That is the failure mode acceptance bands exist to prevent, occurring inside the band-setting
step itself.**

**Fixed 2026-07-31.** A7's band is now **2 °/s/axis** with NRCSD-E retained as a secondary
reference and labelled provisional. **A7 has never run**, so this is a band tightened before
results rather than after — the distinction the whole validation record depends on, and the sheet
states it above the table. The cost is real: A7 is now **2.5x harder to pass**, on a release path
with no multibody model behind it and a payload centre of mass 70 mm off the thrust line.

**The general rule this implies**, added to `validation/README.md`: *when a band cites an external
document, record which document, which revision, and whether a tighter comparator exists in the
same family.* One line, and it would have caught this.

### P31. The repository carries two different inter-shot cadences and reconciles neither: **RESOLVED 2026-08-05 by ADR-020**

> **The ConOps interval is 1200 s.** Adopted in [`docs/adr/020-inter-shot-cadence.md`](docs/adr/020-inter-shot-cadence.md) because it is the number `astro.py`'s conjunction model,
> the realignment period and the deployment safety case were already computed against, so
> adopting it invalidates nothing, while 10-20 s would require re-running A6 against a
> geometry never evaluated. **A13's failed bands are NOT re-declared against it** -- this
> entry's own instruction, that doing so is a band change belonging declared and dated, is
> followed. Rows 3 and 4 remain FAIL; what changed is their operational significance.
Found while costing A13's failure, and it decides whether that failure matters.

| Where | Interval | For what |
|---|---|---|
| `paper/paper.tex` §III-C | **10–20 s** | described as "set by supercapacitor recharge, at a 150–300 W allocation" |
| `analysis/astro.py` `conjunction(spacing_s=1200.0)` | **1200 s** | the spacing the 30-day conjunction analysis actually models |

**Twenty seconds and twenty minutes, in the same repository, for the same event.** They are not
necessarily contradictory — a machine able to fire every 18 s may still be *operated* every
20 minutes — but **nothing anywhere states which is the ConOps**, and two published analyses
depend on different ones. The conjunction geometry, the realignment period and the whole safety
case are computed at 1200 s. The thermal case is argued at 10–20 s.

**The recharge claim is also wrong, which A13 established separately.** The mechanical chain
between shots — index, sled return, attitude settling — has a floor of **18.1 s** at a 6.9 s
return, against a recharge of 8.6 s at 300 W and 17.2 s at 150 W. **Attitude settling binds at
both allocations.** The paper's sentence has been corrected; this entry is about the second
number, which the correction does not touch.

**Why it matters for A13.** At 1200 s the 8.2 s settling is 0.7 % of the interval and A13's band 5
tested against the wrong quantity. At the 18.1 s floor it is 45 % of it. **The same failure is
either irrelevant or dominant depending on a number nobody has written down.**

**What would close it:** state the ConOps cadence once, in one place, with the reason — and make
`astro.py`'s `spacing_s` default read from it rather than carry an independent literal. If the
answer is 1200 s, A13's bands 3–5 should be re-declared against it and re-run; **that is a band
change and belongs declared and dated, not quietly applied to an existing failure.**

### P32. The working Gen4 geometry has no corresponding operating point: HIGH, NEW 2026-08-03

The published Phase I result assumes a uniform 1.30 m active stator and release at 1500 mm.
`EMOCD_Gen4_Open v7` instead places the same 488 mm sled at s = 300 mm stowed and s = 1200 mm
release, a 900 mm acceleration stroke. Its 340 mm Halbach array is fully over the stator only
through s = 1051.5 mm. The final 148.5 mm is a finite-edge region, and 191.5 mm of the array
remains over the stator at release.

The current 16.388 m/s, 10.53 g, 2851 J gross and 20.99% net values are still reproducible for
the frozen Phase I geometry. They are not Gen4 results. No public document may attach them to
the open assembly, and a constant-thrust calculation shortened to 900 mm would not repair the
mismatch because it would ignore the changing overlap.

The provisional stationing does resolve one geometry conflict: release is at s = 1200 mm and
the fin enters the brake at s = 1222 mm, leaving 22 mm between the two events. The fin then has
330 mm of travel through the brake before its trailing edge clears at s = 1552 mm. Those are
kinematic envelope results, not an arrest or thermal validation.

**What would close it:** E27's position-dependent force calculation, followed by one controlled
propagation through power, energy, thermal, braking, orbit, paper and validation records. Until
then the Gen4 export gate stays closed and the Phase I baseline remains the only rated point.

### P33. The paper credits a winding inductance nobody had computed: MEDIUM, NEW 2026-08-05

`paper/paper.tex` says the drive switches at 20-40 kHz, "high enough that the current ripple is
filtered by the winding inductance and low enough to keep switching loss within the converter's
97 J/shot budget." **There was no inductance anywhere in this repository.** No henry in
`analysis/`, and no phase current either: `motor_model.shot()` integrates in *sheet* current
(A/m), and the `I_peak` it reports is the **DC-link current drawn from the bank**, not the
current in a conductor. Every "peak current" figure in this project, including the lever table in
`docs/DESIGN_OPTIONS_exit_velocity.md` and A10's ESR ceiling, is that DC-link number.

The gap is structural rather than clerical. A sheet-current model is turns-invariant: the same
126 kA/m can be wound as many turns at low current or few at high current, L scales as N², phase
current as 1/N, and the stored field energy is the same either way. **So the model cannot
produce an inductance, and the claim above could not have been checked when it was written.**

`analysis/drive_electrical.py` closes it on the one constraint that does fix the turns count:
the inverter has to synthesise the phase voltage the machine demands at rated speed, out of a
96 V bus sagged to 90.9 V. The required volt-amps are invariant under the turns count, so the
design point follows without a new winding assumption.

| | |
|---|---|
| Armature-reaction field energy | **2.058 J** (harmonic sum over the belt distribution) |
| Peak phase current | **373.2 A**, against the 338.8 A DC-link figure quoted everywhere |
| Phase inductance | **19.70 µH** |
| Phase resistance | **25.18 mΩ** |
| Electrical time constant | **0.782 ms**, fast against the 158.6 ms stroke |
| Modulation index at exit | **1.00**, by construction |
| Ripple at 20 kHz | **60.9 A pp, 16.3 % of peak** |
| Ripple at 40 kHz | **30.5 A pp, 8.2 % of peak** |

**Half the paper's sentence survives and half does not.** The loss half is fine: the ripple adds
**3.71 J to an 834.7 J** copper budget at 20 kHz, four tenths of one percent, so nothing in the
thermal or energy record moves. The filtering half does not: **16 % peak-to-peak ripple at
20 kHz is not a filtered current**, and the sentence asserts it of the whole 20-40 kHz range.
Only the top of that range is defensible.

**Two consequences that are not in any document.** First, the SiC devices carry the phase
current, so they are being selected against **373 A** and the repository only ever wrote down
339 A; the paper specifies the 1200 V rating and never a current rating. Second, exit velocity
and phase current are locked together through the bus: more velocity means more back-EMF, which
means fewer turns, which means more current, which lands on the bank ESR ceiling **P26** already
tracks. That coupling is real but it is **not a new velocity ceiling** — the machine can be
rewound for any speed, it just pays in current — and it should not be written up as one.

**What would close it:** a winding layout with an actual turns count, conductor cross-section
and end-turn geometry, at which point L stops being inferred from an energy balance and becomes
a property of drawn hardware. The 2-D energy method here omits end turns entirely, so 19.70 µH
is a **lower bound** and the ripple figures are upper bounds. `docs/PHASE_II.md` PII-7 and the
segmentation decision in **P29** both move it: energising less stator cuts L and R together.

### P34. A payload carrying a magnetometer cannot fly in this magazine: HIGH, NEW 2026-08-05

> **EXTENT BOUNDED 2026-08-05.** `analysis/far_field_sensitivity.py` profiles the field outward
> from the thrust line. It falls below magnetometer full scale only at **z = 251 mm** and below
> Earth's own field at **z = 332 mm**. The 3U payload envelope spans z = 20 to 120 mm, so
> **every part of the payload sits above magnetometer full scale** -- 610.8x at the near face and
> still 3.4x at the far face. This is not a near-face problem with a safe interior; it is the
> whole satellite.

**Found by A14, against a band declared before the run.** The payload's nearest face sits **6 mm**
behind the Halbach array back face — `cad/parameters.json` puts the array back face at z = 14 mm
and a 3U payload at z = 20 to 120 mm — and the static field there is **61.1 mT**. That is
**1357× Earth's field** and **611× the full scale of the class of magnetometer a CubeSat carries
to sense Earth's field.**

**This is a payload compatibility constraint and it is not in the interface specification.**
`paper.tex` §on the interface lists four things VOLLEY asks of a host and publishes a magnetic
keep-out radius for the *host*. Nothing anywhere states what the deployer does to the satellite
inside it. A customer flying a magnetometer, a magnetorquer, a fluxgate, or anything with
soft-magnetic structure is affected, and "the satellite is never modified" — the central claim of
this project — is doing quiet work here that it has not earned.

**What A14 did and did not establish.** The 61.1 mT figure is in the exponential near field where
the model reproduces the 10 mm station exactly, so it is sound. The centre-of-mass and far-face
figures, 0.463 and 0.341 mT, sit in the edge-effect tail that **P3** already records this model
getting wrong, so the *extent* of the affected volume is not established. A14's band 5 is VOID
for that reason and for the absence of a materials list.

**What would close it,** in the order that costs least:

1. **State the exposure.** Compute the field over the payload envelope with a model whose far
   field is trustworthy, which means resolving P3 first. Publish it as a payload environment
   specification rather than a host keep-out.
2. **Decide whether it is a constraint or a defect.** Exposure lasts one shot plus dwell time in
   the cradle, so a saturated magnetometer recovers; **remanent magnetisation of soft-magnetic
   parts does not.** That distinction needs a materials list and is the question worth answering.
3. **T-6** measures it. Its priority rises on this result.

Shielding the payload is the option that should be resisted: it adds mass to the customer's
satellite, which is the modification the architecture exists to avoid.

### P35. The GMAT script generator is pinned to a superseded operating point: LOW, NEW 2026-08-05

`validation/gmat/build_scripts.py` carries `DV = 20.37` under a header saying the operating point
is "identical to `astro.py` __main__ and `conjunction()` defaults". **It is not.** `astro.py`'s
`conjunction()` default is now `dv=16.388`, three corrections later. Anyone regenerating the A5 or
A6 inputs today gets scripts at a velocity the project abandoned on 2026-07-29.

**It is LOW because nothing currently reads it wrongly.** A5 and A6 *were* run at 20.37 and their
sheets say so, so the generator matches the results it produced. The defect is that the file
claims to track `astro.py` and silently does not, which is the same failure class as the stray
`results/sizing.json` and the stale companion generator: **a second copy of an operating point
that nothing regenerates.**

**Deliberately not fixed by editing `DV`.** Changing it would make regenerated scripts differ from
the ones whose results are recorded, which trades one dishonesty for another. A15 therefore got
its own generator, `build_poem_campaign.py`, which reads Δv from `motor_results.json` at run time
and cannot go stale.

**What would close it:** either re-run A5 and A6 at the current point and update the generator
together, or mark `DV` explicitly as the frozen historical value those two analyses were run at
and delete the claim that it tracks `astro.py`. The second is honest and costs nothing.

### P36. The track has no dynamic design case, and A17 says it needs one: HIGH, NEW 2026-08-05

`sizing.py::track_first_mode()` checks the track against one static target -- above 70 Hz to clear
the launch primary band. **A17 shows that is necessary and not sufficient.** Every shot chirps the
force ripple through the 109 Hz fixed-fixed mode, and the mode amplifies it **8.18x** at the
fundamental crossing, twelve times per campaign.

**It does not go away with damping.** Amplification moves from 6.51 at Q = 20 to 8.33 at Q = 500,
so no plausible bolted-aluminium Q rescues it. The governing parameter is the normalised sweep
rate `rate/f^2 = 0.18`, slow enough for the mode to respond fully regardless of Q.

**What the project does not have:** any damping specification, loss factor or Q for the track; a
moving-load model, since the ripple force travels with the sled and A17's SDOF does not represent
that; and a dynamic acceptance criterion beside the static 70 Hz one.

**What would close it:** a damping specification with a measurement behind it, and a moving-load
response model. **T-2's sine sweep becomes a pass/fail qualification item rather than a signature
comparison** on this result, and that belongs in `docs/QUALIFICATION_PLAN.md`.

**Not a kill criterion.** A17's displacement estimate -- 49 % of the +/-0.05 mm gap budget --
rests on an assumed effective mass and the unmodelled moving load, so it shows the coupling
matters without establishing that it breaks anything.

### P37. The retention gates were sized against a quasi-static load, not the launch environment: HIGH, NEW 2026-08-06

**Found by A18 band 9, against a band declared before the run.** `sizing.py` sizes the retention
gate at **5.9 kN** through two D6 A-286 pins at MoS 1.2. Miles' equation on the GEVS protoflight
spectrum (14.1 g_rms, 0.16 g^2/Hz) at the track's 109 Hz fixed-fixed mode gives **11.7 kN at
Q = 10 and 20.2 kN at Q = 30** -- two to three and a half times the load the gates were sized for.

| Q | 3-sigma load | vs sized | MoS |
|---:|---:|---:|---:|
| 10 | 11.7 kN | 1.98x | 0.56 |
| 20 | 16.5 kN | 2.80x | **0.10** |
| 30 | 20.2 kN | 3.43x | **-0.10** |

**The pins may not be undersized; the load case was.** 5.9 kN is quasi-static. Random vibration
through a lightly damped 109 Hz mode is a different problem, and the claimed MoS 1.2 collapses to
0.10 at Q = 20 and goes negative at Q = 30, past the pins' 18.2 kN shear capacity.

**This compounds P36.** Both turn on a structural Q this project has never specified or measured,
and both make the same test decisive. `docs/QUALIFICATION_PLAN.md` already calls T-1 *"the single
most likely qualification failure"*; **it is now a predicted failure rather than a ranked risk.**

**What would close it:** a damping specification with measurement behind it, then resize the gates
against the random-vibration case, or isolate the cassette stack so the mode does not drive the
pins. **This is analysis only -- T-1 closes the test half of E10 and nothing here substitutes.**

> **Not all of these weigh the same.** Three of the entries below are threats to whether the
> machine has a reason to exist rather than engineering work, and they are hard to see in a
> numbered list. [`docs/KILL_CRITERIA.md`](docs/KILL_CRITERIA.md) separates them, with the value
> at which each becomes fatal.

## E: Unsolved engineering

### E1. Three-dimensional field closure: 2-D HALF CLOSED 2026-07-29 by A1
> **A1 has run.** A meshed 2-D magnetostatic FEM (scikit-fem P1, 141 k elements, gmsh) gives
> **K_t = 11.228 N per kA/m against the model's 11.22 (a ratio of 1.0007**) with force
> ripple 1.25 % against 1.26 %. Midgap peak and winding mean both land at ratio 1.001.
> **The thrust band, the one that matters, is met.**
>
> What remains open is the 3-D half: end effects on a 340 mm array of finite 90 mm depth.
> P21 is that limitation showing up directly, the 2-D model overestimates far field because
> it has infinite depth. That needs A2.
`motor_model.py` resolves the winding in 2-D. End effects of a few percent on Kt remain
uncomputed. This is the declared close-out task for the electromagnetic model. The
magnetostatic package now exists, `analysis/femm/emocd_cross_section.dxf` plus
`analysis/femm/FEMM_RUN_SHEET.md` (analysis A1), which supersedes the older
`docs/FEMM_Run_Sheet.md`; the acceptance band in that older sheet predates the
winding-resolved model and should not be used. **Nothing has been run.** A1 closes the
2-D half; the 3-D end effects still need a 3-D solver (Elmer or GetDP are the free
options). Acceptance band declared in `validation/A1_field_femm.md`.

### E2. No FEA confirmation of anything: PARTIALLY CLOSED
> **Two FEA results now exist.** A4 (CalculiX, structural) ran 2026-07-28. **A1 (magnetostatic)
> ran 2026-07-29** and is the one that matters most: K_t had only ever been checked
> analytic-against-analytic, a closed-form wave model against magpylib, both superposing
> analytic solutions for uniform blocks, neither solving a field equation. A1 solves the PDE on
> a mesh and agrees to 0.07 %.
>
> Still open: no FEA of the track, the brake, or the cassette structure; and no 3-D
> electromagnetic solve (E1).
The field cross-check is analytic-vs-analytic (both magpylib and the wave model assume
ironless geometry, where superposition is exact). That is a genuine check of the wave
model but is NOT independent confirmation from a different physical method. Two analyses
are specified and neither has been executed: **A1** magnetostatic (E1 above) and **A4**
sled-chassis structural, which is what P5 and P8 are waiting on. Both, plus A5, A8, are
written up with pre-declared acceptance bands in `validation/`, and A5's GMAT toolkit is
built (`validation/gmat/`) though not yet run. A8 (pulse-power, E17) is
the cheapest of them and needs no CAD, no mesh, and no licence.

### E3. Masses are parametric and unchecked against vendor data
CAD now exists (`cad/`, nine documents), so the "no CAD" half of this item is closed,
but the mass problem is not. `mass_properties.py` still uses primitive solids with
shell/fill factors, and no component mass is checked against a vendor datasheet;
estimate spread perhaps ±15 %. Fusion-computed masses are **not** a substitute: they use
solid-copper stator, solid-aluminium CubeSats, and steel standing in for NdFeB, which is
why they are deliberately excluded from `cad/parameters.json`. The sled mass (4.86 kg)
propagates directly into the headline velocity (see P5 and P8) and the enclosure,
radiator, and avionics are still missing from the rollup entirely (P10).

### E4. No hardware at any level
> **A protocol now exists, 2026-07-29.** `docs/BENCHTOP_TESTS.md` specifies four sub-scale
> experiments, cheapest first, each closing a named claim with its acceptance band declared
> in advance: a Halbach pair on a gaussmeter (B-1), single-coil thrust against
> K<sub>t</sub> (B-2), capacitor discharge against the pulse model (B-3), and a drop-test
> brake coupon against the plate-drag law (B-4). **B-1 costs roughly the price of two magnets
> and would give this project its first measured number.** Full-scale qualification is
> specified separately in `docs/QUALIFICATION_PLAN.md`. None of it is run, this item stays
> open until something is measured.
>
> **Strengthened 2026-07-30, and the reason is competitive.** The Harbin group
> (`docs/PRIOR_ART.md`) has **built and measured a prototype**; this project has not, and that
> difference is visible to any reviewer. B-1 and B-2's bands were declared before any test but
> *chosen* rather than derived. `validation/bench/bench_predict.py` now derives them, importing
> `verify_field.py` and `motor_model.py` with a guard against geometry drift. Measurement error
> comes out at **4.4 % for B-1's field rows and 13.5 % for B-2's thrust**, against bands of ±15 %
> and ±20 %. The bands do not move, they must also cover model error, which is the thing under
> test, but a failure is now interpretable, because the rig can no longer be blamed for it.
> Two procedural traps were found in the process and are documented in `BENCHTOP_TESTS.md`: a
> two-block bench pair built poles-facing reads **exactly zero field**, and B-2's load cell must
> be sized to the smallest force in the sweep rather than the largest.
TRL 2-3. Nothing has been built, fired, or measured. The velocity, dispersion, and
tip-off claims are all model outputs.

### E5. Host stage properties unavailable
Recoil budgets are parametric across 300-900 kg host classes because no candidate
stage publishes its mass and control authority. Cannot be closed from public data.

### E6. Absolute orbital lifetimes are uncertain
Static exponential atmosphere at mean solar activity. Absolute lifetimes swing
severalfold across the solar cycle. The x1.80 ratio was believed invariant and defensible;
**P16 has since falsified the invariance**: GMAT gives 1.73 / 1.78 / 2.07 across low to high
activity. The point value at mean and high activity survives; the invariance does not. `validation/A5_astro_orekit.md` specifies an independent
re-run under GMAT (toolkit built in `validation/gmat/`, Orekit an equally valid
substitute) (different codebases, independently implemented force models) with the band on the ratio and explicitly not on the absolutes. It now also
carries a second leg: reproduce the **measured** decay of 3-5 non-manoeuvring 3U CubeSats
from CelesTrak / Space-Track TLE histories, band 15 % on time-to-decay. Two models
agreeing is weaker than a model reproducing a flown decay, and the flight data is free.

### E7. Velocity dispersion rests on assumed sensor noise
The 0.027 m/s (3σ) result is a closed-loop simulation using an assumed 8 mm/s sensor
sigma and assumed tolerance distributions. No sensor has been selected or characterised.
The separation side of this is specified in `validation/A7_separation_chrono.md`, whose
tip-off band is taken from a flown deployer rather than chosen. **Tightened 2026-07-31 from
5 to 2 °/s/axis**: the band cited NRCSD-E, the external Cygnus deployer, whose 5 °/s its own
publisher calls provisional, while the internal NRCSD that has flown hundreds of times specifies
**< 2 °/s/axis**. Two deployers, not a contradiction, and the band had been set at the easier of
them. See **P30**.

### E8. Brake energy is thrown away
~1.0 kJ per shot dissipated in the fin. Whether any of it is worth recovering (and what
that would cost in mass and complexity) has not been examined since the efficiency
correction.

### E9. 6U/12U variants are force-limited, not designed
The payload family table is arithmetic from the same thrust constant. No mechanism,
cassette, or structural design exists for larger classes.

### E10. Launch restraint is drawn but not analysed

> **ANALYSIS HALF CLOSED 2026-08-06 by A18, and it FAILED.** Miles' equation on the GEVS
> spectrum gives 11.7-20.2 kN through the retention pins against the 5.9 kN they were sized for.
> Opened as **P37**. T-1 closes the test half and nothing here substitutes for it.Retention gate pin sizing exists (two D6 A-286, margin 1.2) and the breech launch-lock
blocks are now modelled in CAD (`cad/parameters.json` `track`: `launch_lock`, x = 30-50
mm, 2 off). The rest, escapement caging, cam lock, tolerance stack-up under vibration,
is drawn or described, not analysed.

### E11. No contamination or outgassing analysis
> **ADR-004 gains external support 2026-07-29:** coreless construction lowers outgassing and
> vacuum-rated ironless linear motors are catalogue products, so this architecture converges
> with fielded vacuum practice. Does not close the item, T-4 tests *this* material set.
> **Specified 2026-07-29** as T-4 in `docs/QUALIFICATION_PLAN.md`: 8 thermal-vacuum cycles,
> −40 to +60 °C, with ASTM E595 limits (TML ≤ 1.0 %, CVCM ≤ 0.1 %) as pass criteria. The
> materials rule B16 already requires E595-compliant selection; T-4 is where that gets tested
> rather than asserted. Not run.
Materials were selected against E595 limits by rule, not by analysis. No contamination
budget for customer optics exists.

### E12. EMC beyond stray field
> **Specified 2026-07-29** as T-6 in `docs/QUALIFICATION_PLAN.md`: MIL-STD-461 RE102/CE102
> class emissions during a 330 A pulse, plus static field measured at the payload envelope
> against the 22.7 / 4.3 / 0.4 mT model. A customer flying a magnetometer or magnetorquer
> needs that number measured, not modelled. Not run.
Static magnetic keep-out is computed. Induced currents from switching transients in
adjacent payloads are discussed but not calculated.

> **Sharpened 2026-08-05, and it is now the oldest unquantified thing in the project.** Two
> separate facts landed on this item on the same day. First, the mid-2025 decision to drop the
> coilgun rested partly on the electromagnetic environment being unacceptable for an unmodified
> CubeSat, and **that judgement has no working behind it** anywhere in my notebooks or here
> ([`docs/HISTORY.md`](docs/HISTORY.md#why-the-coilgun-was-actually-dropped)). Second, my
> sole-authored silo-launch paper lists "electromagnetic coupling" among the challenges its
> abstract says are "identified and analyzed", and its body never returns to the subject
> ([`docs/SKILLS.md`](docs/SKILLS.md)).
>
> **So an architecture was rejected on EMI grounds that were never computed, and the successor
> architecture has never had its own EMI computed either.** The question has also now been asked
> from outside the project, by a systems engineer wanting to know what the emissions do to the
> payload and to the launch vehicle's communications, which is exactly the pair this item covers
> and has never answered.
>
> **SCOPED 2026-08-05 as A14, and it found the dominant term is not the one anyone was asking
> about.** Six of eight declared bands pass, one fails, one is void as declared.
>
> | | |
> |---|---|
> | Induced EMF, 10 cm² loop at the payload's nearest face | **11.8 mV** commutation, **36.0 mV** at 20 kHz ripple |
> | Static Halbach field at the same face | **61.1 mT**, 1357× Earth, **611× magnetometer full scale** |
> | Comms margin below the SiC knee | 56 dB at UHF, 86–102 dB at S-band |
> | Radiation efficiency at the fundamental | 6.0e-8 — the structure cannot radiate at its own drive frequency |
> | Coilgun comparator | **666×** VOLLEY at equal geometry |
>
> **The switching transient is not the problem; the permanent magnets are.** The AC half of this
> item is now scoped and hands off to T-6 for confirmation. The static half became **P34**, which
> is a payload compatibility constraint rather than an emissions question.
>
> Two things A14 established as side effects. **Band 2 passes by only 1.4×** on an
> upper-bound calculation, halving at 40 kHz, which independently corroborates **P33**'s finding
> that only the top of the declared switching range is defensible. And the credible path to a
> launch vehicle's communications is **conducted, through a shared power bus**, not radiated —
> a specification problem, not a physics one.
>
> **E12 is not closed by this.** A14 is a scoping calculation from quantities already in
> `analysis/results/`; nothing in it is measured, and E12 closes on T-6.

### E13. Two numbers in source documents were never traced
- The "780 deg/s" tumble rate from a third-party document. Falsified as
  implausible (would require a ~7.6 m line-of-action offset on a 1 m vehicle) but its
  origin was never found.
- The "1,000+ G hardening" figure, whose context (ground-launch guns) does not apply
  to this design.

### E14. Patent / disclosure: the disclosure has now happened
Concept and results are public (LinkedIn, and this repository, which is now a **public**
repo carrying the scripts and therefore the operating point). No provisional application
was filed first, so this is done and cannot be undone. What remains is not a decision but
a consequence to be handled: any patent route now runs on whatever post-disclosure grace
period applies in each jurisdiction, India and the US have one, most of Europe does not
counted from the earliest public disclosure, not from today. **If a filing is still
wanted, establish that earliest date and take advice quickly.** If it is not, close this
item out explicitly so it stops reading as pending.

### E15. Sponsorship not secured
The build is the declared next step and is unfunded.

### E16. Reference hygiene
Three references in `paper/paper.tex` were flagged verify-before-submission and have
not been fully verified: eddy-damper heritage [15], Yudintsev separation dynamics [17],
and the vibro-impact deployment paper [18]. `docs/RELATED_WORK.md` adds a further list of
comparator sources and tooling, **none of it retrieved and read either**, and it carries
the same rule: fetch before citing. The differential-drag comparator (Foster et al. flown
Planet Labs results) is the one worth chasing first, since the paper's 25-day baseline is
currently a model output rather than a measurement.

### E17. The pulse-power chain: PARTIALLY CLOSED 2026-07-28 by A8, with two findings
**A8 has been run** (ngspice 42, `validation/spice/emocd_shot.cir`). All five declared bands
were met, exit velocity and pulse duration agree to 0.03 % across two different integrators,
peak current +5.98 %, sag +0.18 points, energy +3.59 %. Two findings came out of it anyway:

1. **Quoted sag is state-of-charge, not terminal voltage.** `motor_model.py` models no ESR
   at all; it reports the capacitor's charge depletion, 4.88 %. With a 12 mohm ESR the
   terminal droops to 86.16 V, a **10.25 % total sag**. The servo-headroom argument behind
   the 0.027 m/s dispersion claim is stated against the smaller number.
2. **The `Q_esr = 160 J` default does not reconcile with 12 mohm.** Integral of I^2 dt over
   the shot is 8008 A^2 s, giving 96 J at 12 mohm. The two agree only at about 20 mohm. This
   item asked for a second number against the 160 J; here it is.

The 12 mohm itself appears only in `docs/EMOCD_Computation_Results_C1-C10.md`, which is
superseded. **Datasheets have since been checked against it and it does not survive**: a bank of
this capacitance built from commercial cells is 116 to 185 mohm, and the shot does not close
above 65. See **P26**. This item is no longer about provenance; the number was not merely
unsourced, it was unattainable.

> **Re-run 2026-07-30 (A8-R), then corrected.** Five of six bands met; the pulse-duration row
> that P23 is about passes at 0.03 %. Energy closure failed at 97.0 %, and the cause was the
> gap this item names: 7126.2 A^2 s at 12 mohm is **85.5 J of ESR dissipation per shot** the
> analytic ledger had no term for. That is the second number against `Q_esr = 160 J` this item
> asked for, and it is 1.9x lower.
>
> **`motor_model.py` now carries `R_ESR` and solves for the current at the bank terminal**
> rather than at the capacitor, so the loss is integrated rather than assumed. P24 records the
> propagation. Two things fell out that are worth more than the correction itself:
>
> - **The 5.98 % peak-current deviation this item recorded was the ESR, not the integrator.**
>   Corrected, the analytic model gives 346.77 A against ngspice's 346.8, agreeing to 0.01 %
>   where it previously disagreed by 5 %. Two independent methods now agree on the number that
>   sets the device rating.
> - **The energy budget closed at 100.0 % while missing a real 86 J term**, because the draw it
>   balanced against came from the same model that omitted the loss. Closure tests arithmetic
>   consistency, not physical completeness, and this file had been quoting it as if it tested
>   both.
>
> The sag finding above stands and is unaffected: the quoted figure is still charge depletion,
> and the terminal dip is still additional.

Original item follows.

### E17 (as originally written). The pulse-power chain has never left the analytic model
The supercapacitor bank, the SiC bridge, and the winding exist only as lumped resistances
and ideal switching inside `motor_model.py` and `sizing.py`. Three numbers depend on that
model and nothing else: the **392 A peak current** (which sets the device rating and the
paper's derating discussion), the **4.9 % bank sag** (which underwrites the servo headroom
behind the 0.027 m/s dispersion claim), and the **672 J copper loss** (which carries the
32 % efficiency figure). No transient overshoot at commutation has been computed, and the
`Q_esr = 160 J` default in `sizing.py`, flagged as unsourced during the P2 review before
being traced to the script's own default, has no second number against it.

Specified as **A8** in `validation/A8_pulse_spice.md` (ngspice or PySpice, both free).
This is the least expensive analysis in the plan: no geometry, no mesh, no licence, and it
attacks three headline-adjacent numbers at once.

### E18. Conjunction covariance is invented: NEW 2026-07-27
Any probability-of-collision result (A6) inherits whatever covariance it is given, and no
covariance exists for a satellite that has never flown. Space-Track **Conjunction Data
Messages** carry real post-deployment covariances for comparable objects and are the
defensible source; `validation/A6_conjunction_cara.md` now names them as the preferred
input, with an explicitly documented assumption as the fallback. Until that is done, no Pc
figure from this project should be quoted as anything but conditional on its assumption.

### E19. Eddy-current heating inside the magnet blocks is not modelled: NEW 2026-07-29

> **CLOSED 2026-08-06 by A18, benign by a factor of 400.** 25.2 W of eddy loss in 3.67 kg of
> NdFeB over a 158.6 ms pulse is **0.0025 K per shot, 0.030 K per campaign** against a 1 K band.
> **Segmentation is not needed**: the trade is real for steady-state rotating machines and
> irrelevant to a 159 ms pulse at 341 Hz.> **Cross-industry review 2026-07-29** (`docs/CROSS_INDUSTRY.md`): this is a named, well-studied
> loss mechanism in PM machines, and **magnet segmentation is the standard mitigation, which
> reduces thrust and mechanical robustness.** That is a design option this project did not
> previously have. Item stays open: the literature is steady-state rotating machines, and
> nobody has computed the 157 ms pulsed case here.
`sizing.py::magnet_temperature()` models exactly one thermal effect on the magnets:
reversible remanence drift with ambient temperature, `alpha = -0.11 %/K`. NdFeB is a
conductor (roughly 1.4-1.6 uOhm*m, some 80-90x copper's resistivity but far from an
insulator), and the blocks sweep past the winding at up to 20 m/s through the field's
spatial harmonics, the belt winding's own 6th-harmonic ripple, slot-like content, and
whatever switching harmonics the SiC bridge puts on the current. That drives eddy currents
in the magnet bulk.

This is not the same failure mode as reversible drift. Local heating risks crossing the
knee point and causing **irreversible** demagnetisation, which no amount of cooling
recovers, and it is worst where the field harmonics are strongest rather than where the
bulk temperature sensor would sit.

No number is offered here because nothing in the repo computes one, and inventing an
order of magnitude for a loss that depends on harmonic content the model does not resolve
would be worse than recording the gap. What can be said without computation: this term
grows with current density, so it works directly against the "raise sheet current to
213 kA/m" option in `docs/DESIGN_OPTIONS_exit_velocity.md`, which that document already
calls thermally hard for the winding alone.
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

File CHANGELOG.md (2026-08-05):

# Change log / audit record

Every change made to this repository after the initial export is recorded here, so that
each edit can be traced to a cause and a source of truth. This file is deliberately
exhaustive: it exists to be audited later.

Read alongside `docs/PROVENANCE.md` (what stands behind each claim), `OPEN_PROBLEMS.md` (the defect
list these changes close) and `docs/DECISION_LOG.md` (why design choices were made).

---

## 2026-08-05 (second pass): reading the silo paper, and what it says about ADR-003

| ID | Item | Detail |
|---|---|---|
| ADR3-01 | **ADR-003's armature clause was wrong and my own other paper is what shows it** | It rejected the coilgun partly because "it needs a conductive armature, either bolted to the customer satellite or separated as a sabot with its own release event." That is a false choice. *Electromagnetic Launch System for Vertical Silo-Based Missile Deployment* considers exactly this trade and selects an **inductive cradle** — reusable, never carried by the payload — over a conducting sabot, to avoid rail ablation and suit repeated cycling. Architecturally that is the same move as this project's reusable sled. Struck rather than rewritten, because it was doing rhetorical work it could not support. |
| ADR3-02 | **The decision is unaffected** | The load-bearing reasons were never about where the conductor sits: sequential coil triggering is fire-and-commit against a synchronous machine commanding current on measured position, and Feng et al. run 1352 g mean against 10.53 g here. Both were already stated in the ADR and both stand. `docs/SKILLS.md` points readers at both papers, so a reader could have found this before I did. |
| SILO-01 | **Two of Table III's four rate-of-fire rows do not follow from its own caption** | The caption fixes `t_index = 1.5 s` and the text gives `t_cycle = E_input/P + t_index`. The 1 MW optimistic row prints **18.5 rounds/min** where the stated method gives **15.00** (it implies t_index = 0.74 s), and the 500 kW optimistic row prints **8.6** where the method gives **9.23** (implying 1.98 s). The 18.5 propagates into that paper's abstract and conclusion, so its headline cadence is high by 23 %. `SKILLS.md` had already corrected the 1 MW figure; the 500 kW row had not been noticed. Recorded in `docs/SKILLS.md` because that paper has no defect log of its own. |
| SILO-02 | **Its abstract claims an EMI analysis its body does not contain** | The abstract says g-load tolerance, **electromagnetic coupling** and pulsed-power thermal management "are identified and analyzed". Section IX lists six challenges and electromagnetic coupling is not among them. |
| E12-01 | **The pair is the argument for closing E12** | Two electromagnetic launch studies and no EMI calculation in either: one dropped an architecture partly on electromagnetic grounds it never computed, the other lists the analysis in its abstract without performing it. The question has now also been asked from outside the project. E12 records what a first-pass scoping calculation needs and notes that **P33 has just supplied the missing inputs** — phase current and winding inductance — so the `dI/dt`, the field at the payload envelope, the induced EMF and the spectral knee are all computable from `analysis/results/` without new apparatus. T-6 remains the measurement. |

**What authorised it.** ADR3-01 is a correction to a published argument in an architecture
decision record, which is the class this project fixes in place with the original struck and
visible. The SILO items are defects in a document cited on my CV and described in `SKILLS.md`;
recording them where the paper is described is the only defect log it has. No VOLLEY operating
point, band or verdict moved.

---

## 2026-08-05: the coilgun's real rejection reason, and the inductance behind it

| ID | Item | Detail |
|---|---|---|
| HIST-01 | **The recorded reason for the pivotal architecture change was incomplete** | `DECISION_LOG.md` and ADR-003 both explained the mid-2025 coilgun-to-LSM switch through velocity accuracy. My 2021-2025 notebooks give two different reasons and they come first: the acceleration is enormous and the electromagnetic environment is severe, and either one defeats the point of carrying an **unmodified** CubeSat. Added to `docs/HISTORY.md` in the notebook's own words, with the seven constraints the motor answered at once. |
| HIST-02 | **One half of that judgement is now a number and the other never was** | ADR-003 already carries the acceleration comparison: Feng et al. run 1352 g mean over a 3.9 m barrel against this design's 10.53 g peak. **The EMI half has no working behind it anywhere**, in this repository or the notebooks. It was an instinct about pulsed megaampere discharges beside unshielded commercial electronics. `E12` already records the near half of the gap; the file now says so rather than implying the decision was quantified. |
| P33-01 | **`paper.tex` credited a winding inductance that did not exist** | The drive section said 20-40 kHz is "high enough that the current ripple is filtered by the winding inductance". There was no henry anywhere in `analysis/`, and no phase current either: `motor_model.shot()` integrates in *sheet* current and its `I_peak` is the **DC-link** current, not a conductor current. Logged as **P33**. |
| P33-02 | **The model cannot produce an inductance, which is why nobody had** | A sheet-current model is turns-invariant: the same 126 kA/m winds as many turns at low current or few at high, L scales as N², phase current as 1/N, stored field energy is unchanged. The claim could not have been checked when it was written. |
| P33-03 | **The bus closes it** | `analysis/drive_electrical.py`. The inverter must synthesise the phase voltage the machine demands at rated speed from a 96 V bus sagged to 90.9 V, and the required volt-amps are invariant under the turns count, so the design point follows with no new winding assumption. Armature field energy **2.058 J** by harmonic sum over the actual belt distribution; **373.2 A** peak phase current, **19.70 µH**, **25.18 mΩ**, τ = **0.782 ms**, modulation index 1.00 at exit. |
| P33-04 | **Half the paper's sentence survives** | Ripple adds **3.71 J to an 834.7 J** copper budget at 20 kHz, so the loss claim is fine and no thermal or energy number moves. But ripple is **16.3 % peak-to-peak at 20 kHz** and 8.2 % at 40 kHz, and 16 % is not a filtered current. The sentence asserted it of the whole range; only the top of the range is defensible. Corrected in the manuscript and the PDF rebuilt. |
| P33-05 | **Two things nobody had written down** | The SiC devices carry **373 A**, not the 339 A quoted everywhere, and the paper specifies a 1200 V rating and no current rating. And exit velocity couples to phase current through the bus, landing on the ESR ceiling **P26** already tracks. That coupling is **not** a new velocity ceiling and is not written up as one: the machine can be rewound for any speed, it just pays in current. |
| STALE-01 | **`KILL_CRITERIA.md` §5 still carried the superseded A13 conclusion** | The 2026-08-03 correction reached §6 but not §5, which went on quoting 0.16 °/s residual, an 8.2 s null, an 18.1 s cadence floor and the counter-mass route. Rewritten to the corrected transient-rate result, with the withdrawn cadence conclusion stated as withdrawn. |
| STALE-02 | **`DECISION_LOG.md` cited a comparator struck four lines above it** | The line read "32 % electrical-to-payload efficiency against the coilgun's 1-2 %". The 1-2 % was withdrawn on 2026-07-30 and never removed here, and 32 % predates both the sled-mass adoption and the quadrature correction. Replaced with 20.99 %, and the efficiency comparison is explicitly **not** restated as a reason for the decision, because Feng's 14.9-19.9 % is this design's own range. |
| STALE-03 | **ADR-003 carried a pre-quadrature operating point and called A1 unrun** | 10.7 g and 2.80 kJ moved to 10.53 g and 2.85 kJ gross / 2.56 kJ net. Its validation note still called Kt "checked only analytic-against-analytic" and A1 "the top roadmap item"; A1 has run and agrees to 0.03 %. |
| STALE-04 | **Counts and per-satellite mass** | 31 numbered defects to **33** in `KILL_CRITERIA.md`, 32 to **33** in `ROADMAP.md`. The 6.41 kg per satellite in `KILL_CRITERIA.md`, `MARKET.md` and `PAYLOAD_CLASSES.md` prose predated the brake-fin correction; `payload_family.json` gives **6.375**. `BASELINE.md` was stamped at `d82877a` while carrying post-`d82877a` values, and is regenerated. |

**What authorised it.** HIST-01 and HIST-02 are record corrections: the repository stated an
incomplete reason for its most load-bearing decision. P33 is a defect in a published claim, which
`docs/BASELINE.md` change control admits as Phase I error correction. No operating point, band or
verdict moved; the ripple loss is four tenths of one percent of the copper budget and the frozen
baseline still holds at 23 values. The STALE items are propagation the 2026-08-03 audit missed.

---

## 2026-08-03: Gen4 open assembly recorded before performance propagation

| ID | Item | Detail |
|---|---|---|
| G4-01 | **The working CAD and the analysed baseline are now separate states** | `EMOCD_Gen4_Open v7` uses the 488 mm sled at s = 300 mm stowed and s = 1200 mm release. The committed STEP, STL, renders, paper and operating point remain the Phase I / Gen3 record. I recorded the split in `docs/GEN4_STATUS.md` instead of attaching the Phase I numbers to new geometry. |
| G4-02 | **The 900 mm stroke reaches the finite stator edge** | The 340 mm Halbach array is fully over the stator only through s = 1051.5 mm. The final 148.5 mm of acceleration is under partial overlap, with 191.5 mm of array overlap left at release. A shortened constant-thrust calculation would not represent the CAD. P32 and E27 keep the missing operating point visible. |
| G4-03 | **Release and brake entry no longer overlap in the provisional stationing** | The fin leading face reaches the brake at s = 1222 mm, 22 mm after the provisional release station. Its trailing face clears the brake at s = 1552 mm, giving 330 mm of interaction travel. This is a geometry result only; brake force, thermal response and arrest remain unvalidated. |
| G4-04 | **The explanatory assembly stays open** | The enclosure is a separate envelope-check configuration. The named operational export selection excludes audit, linked-source, duplicate-brake, construction and released-payload reference occurrences. No Gen4 STEP, STL or render has been exported, and the export gate remains closed pending the finite-stator run. |
| G4-05 | **The twelve-payload stowed manifest is present in Fusion** | Six port and six starboard payload occurrences are present. That closes the missing-occurrence CAD housekeeping item only; it does not establish mass, feed-mechanism or interference closure. |

**What authorised it.** The Fusion configuration changed the geometry on which thrust, release
and arrest depend. I recorded the observed state and its consequences without changing a Phase I
number. ADR-019 keeps the successor assembly separate until the affected calculations are run.

---

## 2026-08-03: full numerical audit corrections

| ID | Item | Detail |
|---|---|---|
| AUD-01 | **Shared thrust quadrature corrected** | The reference model and A1 FEM post-processor both used endpoint-inclusive samples with an unweighted thickness divided by sample count. I replaced that invalid rule with nine-point Gauss-Legendre quadrature. Kt moves 11.22 to **11.03 N per kA/m**, ripple 1.26 to **0.99%**, velocity 16.537 to **16.388 m/s**, and net efficiency 21.16 to **20.99%**. A1 remains PARTIAL on its original two field misses. |
| AUD-02 | **A13 residual-rate conclusion superseded** | Internal mass motion produces transient host counter-rotation and an attitude offset; it does not leave ideal rigid-body rate after the mass stops. Rows 3 and 4 remain FAIL at **0.136 deg/s** for 500 kg and **0.443 deg/s** for 200 kg. Row 7 is VOID. The 8.2 s rate-null and 18.1 s cadence floor do not follow and are superseded. |
| AUD-03 | **A6 bound repaired** | The 3.7e-8 result swept one fixed 5:1:1 covariance shape and was not a bound over all covariance. At the old 14.49 km geometry an anisotropic case reaches 1.67e-4. At the corrected rated geometry, 54.9 km, a one-dimensional Gaussian slab gives a valid covariance-independent upper bound of about **4.4e-5**. P1 remains open because the propagated geometry is fragile and no CDM exists. |
| AUD-04 | **A12 stress plane extended** | The 340 x 90 mm plane omitted fringe stress. A 600 x 220 mm plane converges to **2680.0 N**, within 0.25% of the 2686.6 N volume-force result. The adopted conservative force and five-of-five verdict stand. |
| AUD-05 | **Mass and thermal ownership corrected** | The Gen3 sled already includes the 0.344 kg moving copper brake fin, which the dry-mass rollup counted again inside a 1.20 kg brake lump. Dry/loaded mass moves to **76.5/124.5 kg**. The thermal model also used a 300 mm fin against the CAD's 120 mm; the per-shot adiabatic rise moves from 3 K to **7 K**, and the twelve-shot no-cooling bound is about **85 K**. No between-shot cooling claim remains. |
| AUD-06 | **Old recoil table corrected** | Twelve shots at 65.552 N s are **786.6 N s**, not 0.98 kN s. The paper's host recoil table still carried the older 20.4 m/s operating point even though its caption said 66.1 N s; the rows now use the corrected impulse. |
| AUD-07 | **Evidence language tightened** | A1 and A12 are independent numerical/model-to-model checks. Neither is experimental validation. A7 remains outstanding and its 3.9 deg/s analytic tip-off exceeds the adopted 2 deg/s comparator. The current 1.62 lifetime multiplier has not been independently rerun in GMAT; A5 reproduced the earlier operating point. |

**What authorised it.** Every item above corrects arithmetic, numerical integration, physical
interpretation, geometry ownership, or evidence language against repository inputs. I did not
move any declared acceptance band after seeing a result. FAIL, PARTIAL, VOID, superseded results,
and open hardware requirements remain visible.

---

## 2026-07-31 (fifth pass): costing A13's failure found a wrong cause and a second cadence

| ID | Item | Detail |
|---|---|---|
| FIX-01 | **The disturbance costs cadence, not pointing** | Peak attitude rate during an index cycle threatens nothing — **nothing is fired during an index cycle.** What matters is residual rate *at trigger*, which is settling against the interval. So the failure is priced in seconds of cadence, and that is computable. |
| FIX-02 | **The sled return duration has an optimum, and 6 s was on it by luck** | Settling falls as `1/T` while the return grows as `T`, so `index + return + settle` has a minimum: **18.1 s at a 6.9 s return.** The 6 s originally assumed sits almost exactly there, which nobody designed. |
| FIX-03 | **A published claim fell out of costing it** | `paper.tex` §III-C said *"Cadence is set by supercapacitor recharge, 10–20 s at a 150–300 W allocation."* Recharge is **8.6 s at 300 W** and **17.2 s at 150 W**; the mechanical chain floors at **18.1 s**. **Attitude settling binds at both allocations** and the paper attributed the cadence to the wrong subsystem. The 10–20 s *range* survives, which is why nobody checked — **the number looked right, so the cause went unexamined.** Corrected. |
| P31-01 | **The repository carries two inter-shot cadences and reconciles neither** | `paper.tex` §III-C says **10–20 s**. `analysis/astro.py` models the deployment at **`spacing_s = 1200.0`** — twenty minutes — and the conjunction geometry, realignment period and safety case are all computed at it. **Twenty seconds and twenty minutes, same event, same repository.** Logged as **P31**. |
| P31-02 | **Which one it is decides whether A13 matters at all** | At 1200 s the 8.2 s settling is **0.7 %** of the interval and the failure is irrelevant. At the 18.1 s floor it is **45 %** and it dominates. **The same result is negligible or binding depending on a number that appears nowhere.** |
| FIX-04 | **The three routes, costed** | **Accept the 18.1 s floor**: free if the ConOps cadence is ≥ 18.1 s, and free thirty times over at `astro.py`'s own 1200 s. **Raise host control authority**: 0.5 N·m → 10.2 s floor, but it is a fifth item on a four-item interface spec and narrows the host set the generic-interface positioning depends on. **Counter-mass**: removes the momentum at source and costs **~9.4 kg**, taking 6.41 kg/satellite to 7.2 on a design already failing kill criterion 1. |
| FIX-05 | **The bands stay failed** | Routes 1 and 2 give time to null the rate; they do not reduce it. Bands 3 and 4 asked about the rate itself and **that is still 0.161 °/s at 500 kg**. A legitimate answer to the operational question is not an answer to the declared band. Nothing here touches structural ringing either, which is the other half of E24. |

**What authorised it.** FIX-03 is an error correction to a published claim about which subsystem
sets an operating parameter. P31 records an inconsistency rather than resolving it — resolving it
is a ConOps decision, and re-declaring A13's bands against a 1200 s interval would be a band
change and belongs declared and dated rather than quietly applied to an existing failure.

---
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

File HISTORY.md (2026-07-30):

# Project history

> ## This git history was reconstructed on 2026-07-29
>
> The project began on **22 March 2021**. It was not under version control until
> **23 July 2026**, when the working files were exported into this repository. The commits
> before that export date were created during the reconstruction and **their author dates are
> design-period markers, not original commit times**, there were no original commits to
> preserve.
>
> Git records this itself: every reconstructed commit carries an **author date** at its design
> period and a **committer date of 2026-07-29**. `git log --format='%ad | %cd'` shows both.
>
> **Four of the six milestones below are approximate.** Where the record fixes a date, it is
> marked *documented*. Where it only gives a range, `cad/CHANGELOG_CAD.md` says of Gen1,
> "Date range: 2021-2025 (exact build history not reconstructed)", the date is an inference
> and is marked *approximate*. None of these approximations should be cited as fact.

---

## Milestones

| Tag | Author date | Precision | What it marks |
|---|---|---|---|
| `v0.0-concept` | 2021-03-22 | **documented** | Concept, built around a coilgun. Presented at ARDE / INSARM 2021 |
| `v0.1-lsm` | 2025-07-01 | *approximate*, "mid-2025" | Coilgun to linear synchronous motor. The pivotal decision |
| `v0.2-gen1` | 2025-09-15 | *approximate*, see note | Gen1 CAD, 11 STEP files. The geometric ancestor of the parameter set |
| `v0.3-gen2` | 2026-02-15 | *approximate*, range 2025-2026-07 | Gen2 CAD, first structured revision |
| `v0.4-gen3` | 2026-07-23 | **documented** | Gen3 CAD build session; repository export |
| `v1.0` | 2026-07-29 | exact | Current published state |

### Note on Gen1's placement

`cad/CHANGELOG_CAD.md` gives Gen1 a range of 2021-2025 and states its build history was never
reconstructed. It is placed here **after** the mid-2025 motor decision rather than earlier in
that range, because of what the files contain: `EMOCD_Stator_Gen1.step` and a Halbach-array
sled are linear-motor geometry. A coilgun design has no stator. The placement is therefore
**inferred from the artifacts, not read from a record**, if the true date is earlier, this
file is wrong and the CAD changelog's range is the authority.

---
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

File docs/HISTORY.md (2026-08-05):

# Project history

> ## This git history was reconstructed on 2026-07-29
>
> The project began on **22 March 2021**. It was not under version control until
> **23 July 2026**, when the working files were exported into this repository. The commits
> before that export date were created during the reconstruction and **their author dates are
> design-period markers, not original commit times**, there were no original commits to
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

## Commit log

2026-07-29 cost, test plans, and A9 -- the three gaps the reviews found
    analysis/cost.py contradicts the paper, which is the point of building it.
    The paper said recurring hardware "is dominated by the magnet set and the
    SiC drive". A bill of materials driven by mass_properties.py's own part list
    says otherwise: avionics 23.7 %, supercapacitors 17.8 %, SiC 13.3 %, NdFeB
    4.8 %. Doubling the magnet price still leaves it under a tenth of the total,
    so the ordering survives the price uncertainty even though the total does
    not -- this is an avionics and energy-storage cost problem, not a magnetics
    one, which is the opposite of where the design effort has gone. Paper
    corrected and PDF rebuilt.
    Every price i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
2026-07-29 docs: reconcile README/OPEN_PROBLEMS/CHANGELOG with completed CAD (P5-P10)
    - README: 'no CAD' claim replaced; headline table flagged pending CAD structural
    reconciliation (P8); cad/ and analysis/femm/ added to layout. Computed numbers unchanged.
    - OPEN_PROBLEMS: new CAD-reconciliation P-section P5-P10 (sled mass, brake position,
    17.88 m/s provisional, envelope overrun, incomplete mass rollup); P6 resolved via CDS rails.
    - CHANGELOG: dated CAD-integration session in before/after style.
    No number in analysis/*.py or paper/paper.tex changed.
2026-07-29 docs: add wiki home page, consolidate provenance and project notes
    - wiki/Home.md: landing page for the GitHub wiki. Summarises the concept,
    maturity, headline results (with the P5/P8 CAD sled-mass caveat carried
    over), locked decisions, layout, reproduction steps and open problems.
    Absolute GitHub links so it renders in-repo and on the wiki alike.
    - PROVENANCE.md rewritten around verification status: what is model output,
    where a genuine cross-check exists, what was found wrong and corrected.
    - INVENTORY.md: drop the per-row provenance column, refresh C6 (CAD now
    exists) and the open-problems summary (P5-P10).
    - CHANGELOG.md: drop the marker legend and per-row provenance cells; ta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
2026-07-29 docs: archive earlier paper build, link the live Fusion model
    - paper/archive/EMOCD_submission_uncorrected.pdf: an earlier compile of the
    conference paper, predating the 2026-07-23 corrections. It still carries the
    P1-P4 values (323 A peak current, 23 A/mm2 at 140 kA/m, 37 K per-shot fin
    rise, 45.3 km conjunction minimum), so it is filed under paper/archive/ with
    a README tabulating the deltas rather than alongside the current PDF.
    paper/EMOCD_IEEE_Conference.pdf remains canonical.
    - cad/README.md: added the Fusion 360 web-view link under "Live model", with a
    note that the committed STEP files and parameters.json are what the repo
    stands behind.
    - CHANGELOG.md: ARC-01, ARC-02.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
2026-07-29 docs(open-problems): review pass, add P11, refresh stale E-items
    - P11 (NEW, UNCONFIRMED): the archived build carries all four P1-P4 values and
    is named as the submission. If it is the version of record, the corrections
    live only in this repo and need a corrigendum rather than a commit.
    - E3: the "no CAD" half is closed by cad/; masses are still parametric and
    unchecked against vendor data, and Fusion masses are proxies that cannot
    substitute. Points at P5, P8, P10.
    - E1: the FEMM package now exists (analysis/femm/, superseding the older
    docs/FEMM_Run_Sheet.md) but has not been run; A1 closes the 2-D half only.
    - E2: names the two specified-but-unexecuted analyses, A1 and A4.
    - E10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
2026-07-29 docs: repository-wide consistency sweep, add P12
    Swept every committed .md/.tex/.json for values superseded by A27-A30 and the
    P1-P4 corrections, leaving alone the files that quote old values on purpose
    (CHANGELOG, OPEN_PROBLEMS, PROVENANCE, paper/archive, legacy).
    - docs/EMOCD_Computation_Results_C1-C10.md marked SUPERSEDED with an
    old->current mapping table. It read as current computation notes while
    quoting a 4 kg sled at 45 kA/m (22.4 m/s at 19.7 g, 463 A, 3sigma 0.054 m/s,
    <B> 0.62 T), and its 52 % efficiency line is the falsified 55 % regen credit
    that A25/A27 corrected to 32 %.
    - INVENTORY: D5 flagged superseded; D8 repointed to the current FEMM sheet.
    - Issue template: worke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
2026-07-29 docs(related-work): add EML venue, Inductrack precedent, flight decay data, SPICE
    - IEEE EML Symposium / Trans. Plasma Science as the natural venue.
    - Post & Ryutov Inductrack and NASA MagLifter as the architectural precedent
    a reviewer will ask this work to distinguish itself from.
    - CelesTrak / Space-Track: validate astro.py against measured decay of real
    3U CubeSats rather than only against another propagator; CDMs give A6 a
    real covariance instead of an assumed one.
    - ngspice / PySpice as an independent check on the 392 A peak and 4.9 % sag.
    Same rule as the rest of the file: none of it retrieved and read yet.
2026-07-29 docs(open-problems): add E17 and E18, extend A5/A6, add A8 pulse-power check
    - E17 (new): the pulse-power chain has never left the analytic model. The
    392 A peak, the 4.9 % bank sag and the 672 J copper loss all rest on lumped
    R and ideal switching; no commutation overshoot has been computed and the
    Q_esr = 160 J default has no second number against it. Specified as A8.
    - E18 (new): conjunction covariance is invented, and any Pc result inherits
    it. No Pc figure may be quoted except as conditional on its assumption.
    - A8 (new): validation/A8_pulse_spice.md, ngspice or PySpice, with bands on
    peak current, sag, energy drawn, copper loss, pulse duration and closure.
    Cheapest analysis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
2026-07-29 feat(validation): add GMAT toolkit for A5 and the A6 ephemeris input
    validation/gmat/ holds two GMAT script templates, a builder and a parser.
    Nothing has been run; this is the toolkit, not a result.
    - emocd_lifetime.script.tmpl: baseline 450 km circular vs the boosted ellipse,
    propagated to a 120 km perigee under MSISE90 / 20x20 gravity / RK89, one
    filled script per solar-activity level.
    - emocd_fleet.script.tmpl: 12 shots at 1200 s spacing plus the host stage,
    30 days, one CCSDS OEM per object. This is A6's input and replaces
    astro.py's Kepler + secular-J2 propagate() for the conjunction geometry.
    - build_scripts.py imports boosted_elements() and _kepE() from analysis
    /astro.py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
2026-07-29 feat(cad): import three CAD generations, replace mixed/stubbed STEP set
    The committed cad/step/ set matched no single CAD generation and two of its
    files were stubs: the stator STEP held ONE solid where the current geometry
    holds 162 conductors, and the ESPA interface held one where it holds six
    plus bolt holes. cad/README.md meanwhile claimed "STEP exports of every
    document". Anyone opening the committed stator to check the winding layout
    would have found a block. Logged as P13, resolved by this import.
    Replaced by the three audited generations from EMOCD_figs.zip:
    cad/step/gen3/ current: 9 components + EMOCD_Gen3.step monolith (395 solids)
    cad/step/gen2/ heritage: mechanism detai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
    [EMOCD_Assembly.step, EMOCD_Brake.step, EMOCD_Enclosure.step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]
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2026-07-29 fix(docs): absolute asset URLs on the Pages site
    Pages deploying from main -> /docs publishes only the contents of docs/ as
    the site root, so the ../cad/renders/ and ../paper/figures/ paths pointed
    above the published root. All nine images and the paper link would have
    404'd on the live site while resolving correctly in a local browser.
    Switched to raw.githubusercontent.com URLs, matching what wiki/Home.md
    already does and for the same reason. Logged as VIS-08.
2026-07-29 feat: native charts across the repo, and GMAT actually run
    GMAT R2022a installed and run headless. First result in this project produced
    by something other than its own scripts.
    - Bounded 30-day leg: fitted decay rate -0.1618 km/day (GMAT) vs -0.1216
    (astro.py), 1.33x faster. Reported SMA is osculating with 12.2 km
    peak-to-peak short-period variation, so the comparison is a least-squares
    rate over 31 samples, not a difference of endpoints.
    - Full decay, high activity: baseline 144.51 d, boosted 250.03 d, multiplier
    1.7302 against the x1.80 claim - deviation -3.88 %, inside the +/-5 % band
    declared before the run. The absolute lifetime does NOT agree (144.5 vs
    190 d), which is th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
2026-07-29 validate(A4): run the structural FEA, and correct the front pages
    A4 structural leg run with CalculiX ccx 2.21 on the Gen3 chassis plate,
    29,312 nodes, 143,930 quadratic tets, loaded with the 3672 N Maxwell
    attraction from sizing.json. Support bracketed pinned vs clamped.
    All three declared bands pass:
    airgap closure 0.0194 mm vs 0.025 mm per plate (78 % of budget)
    von Mises 33.7 MPa vs 587 allowable (17x margin)
    first mode 3408 Hz vs >200 Hz (17x)
    The plate as drawn is sound - and that is exactly why the velocity problem
    stands. A4 answers "does the drawn chassis meet the constraint" (yes), not
    "what is the lightest chassis that does". Uniform thinn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
2026-07-29 validate(A5): GMAT falsifies the invariance claim the paper calls defensible
    All three solar-activity legs reached the 120 km floor. Two pass the band
    declared before the run; the third does not:
    high (F10.7 250) 1.7302 -3.88 % pass
    mean (F10.7 150) 1.7750 -1.39 % pass
    low (F10.7 70) 2.0739 +15.21 % FAIL
    Spread 18.48 % against a <=5 % invariance band. A5's verdict is FAIL.
    The mechanism was tested rather than guessed. astro.py represents solar
    activity as a uniform multiplicative scale on density, and sweeping that
    scale over a 40x range moves the multiplier only 1.7992 -> 1.7968. A
    uniform density factor divides both lifetimes by the same number, so the
    ratio is invariant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
2026-07-29 analysis: adopt the measured 9.445 kg sled -- the A4 decision rule fired
    First time a value in analysis/ has moved. It is authorised by a rule
    declared in validation/A4_sled_structural.md BEFORE the analysis ran:
    <= 5.35 kg parametric model stands, 20.37 m/s holds
    5.35-6.80 kg neither estimate right
    >= 6.80 kg 17.88 m/s becomes the headline, the paper changes materially
    A4 has run and all three structural bands pass, so nothing forces a lighter
    chassis; P15 measured 9.445 kg from the Gen3 STEP solids. The >= 6.80 branch
    fired, so the scripts move first and the paper follows -- the standing rule
    is kept, not inverted. 9.445 kg is as-drawn and unpocketed; a rib-stiffened
    redesig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
    [motor_results.json]
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2026-07-29 Baseline: EMOCD design-study repo as exported
    Analysis scripts, IEEE paper (LaTeX + compiled PDF), figures, and the full
    provenance/inventory/decision documentation, exactly as produced in the original
    chat session (TRL 2-3, AI-generated, unverified by hardware/FEA/review). This is
    the pre-audit state; subsequent commits correct the paper against the scripts and
    add repo hygiene. See CHANGELOG.md (added later) for the full change record.
    Note: two binary artifacts regenerated during the audit (paper/figures/F06_conj.png
    and the compiled PDF) are introduced in the following commit alongside the paper
    corrections, not here.
    [motor_results.json]
2026-07-29 fix(paper): correct P1-P4 and current density against the scripts
    The scripts in analysis/ are the source of truth. Corrected every paper value that
    its own scripts did not reproduce:
    - P1 conjunction: removed the fragile 45.3 km minimum (a near-resonant beat sample,
    swings 4.6-63 km over +/-2.5% ejection velocity); reframed around the robust 8.1-day
    realignment, mandatory per-shot COLA, and stage disposal before first realignment.
    - P2 peak current: 323 A -> 392 A (motor_model.py I_peak).
    - P3 stray field: 4.7->4.3 mT (20 mm), 1.0->0.4 mT (50 mm) (verify_field.py).
    - P4 fin rise: 37 K/shot -> 3.0 K/shot; 37 K recast as the 12-shot campaign bound
    (sizing.py).
    - Current density: 23 ->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
2026-07-29 docs: close P5, P8, P12 and P15; refresh the ledger and the smaller docs
    P5 and P8 are resolved by the propagation, P15 by adoption, P12 by the paper
    edits. Each keeps its original text below a resolution note, as the P1-P4
    entries do -- the audit trail is the point of this file.
    P5 carries a caveat forward rather than closing clean: 9.445 kg is the
    as-drawn, unpocketed geometry and A4 reports a 17x stress margin, so a
    rib-stiffened chassis would recover mass and nobody has designed one. That
    successor question now lives under E2 and on the roadmap instead of being
    buried in a closed item.
    VALIDATION_REPORT's conclusion was written while the sled conflict was open
    and said neither finding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
2026-07-29 changelog: record the propagation
    Fourteen entries covering the first time a value in analysis/ has moved,
    what the change surfaced (a saturated servo, pasted loss literals, a
    capacitor target the bank no longer meets), the figure generator that had to
    exist before the paper could follow, and the four presentation gaps.
    Records explicitly that the committed PDF is knowingly stale, and why
    declaring that is better than a silent split between source and build.
2026-07-29 paper: rebuild the PDF from the corrected source; add HISTORY.md
    TeX Live 2023 installed in this environment, so the stale-PDF notice in
    paper/README.md is no longer true and has been removed. pdflatex run twice:
    10 pages, zero undefined references, zero missing figures. Verified the build
    came from the corrected source -- the PDF's rated velocity reads 16.5 m/s,
    the ESPA envelope is stated as a requirement the geometry does not yet meet,
    and the only surviving mentions of 20.4 m/s and of invariance are the
    explicit historical references.
    HISTORY.md documents the project timeline from 22 March 2021 and, more
    importantly, states that the git history below the 2026-07-23 export was
    reconstruc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
2026-07-29 cad: Gen2 -- first structured revision
    Rebuilt from the parameter set rather than edited from Gen1. Adds the
    retention-gate pins absent in Gen1 and corrects the sled chassis length.
    Several Gen1 defects carry forward; all are tracked in cad/CHANGELOG_CAD.md.
    Reconstructed commit -- see HISTORY.md. Author date APPROXIMATE, within the
    documented 2025 to 2026-07 range.
    [EMOCD_Assembly_Gen2.step, EMOCD_Brake_Gen2.step, EMOCD_Enclosure_Gen2.step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]
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2026-07-29 governance: adopt the Engineering Programme Dossier and freeze the Phase I baseline
    The dossier and TRB prompt govern this programme and existed only as
    uploads. A repository whose authoritative record lacks the document
    governing it has a hole exactly where this project claims strength. Both are
    now committed verbatim under docs/programme/ and are not edited in place.
    docs/programme/ADOPTION.md records two authorised amendments rather than
    letting practice quietly diverge from the governing text:
    1. Repositories 2-4 created in Phase I, against dossier §3's "Future"
    designation. §4's four-part test was applied rather than skipped, and
    the reasoning is recorded: §2 requires t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
2026-07-29 adr: seventeen architecture decision records, as both governing documents require
    The repo had none. docs/DECISION_LOG.md is good narrative but is
    chronological prose with no status, alternatives or consequences fields, and
    it stops before this week's decisions.
    It is NOT superseded -- it remains the better document for understanding how
    the project got here, and its prose became the Context sections. The ADRs
    are the structured view: what was decided, what lost, what it costs, and how
    we would find out it was wrong.
    001-011 convert the existing decisions. 012-017 record decisions that were
    never written down anywhere:
    012 adopting the measured 9.445 kg sled, and the three second-order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
2026-07-29 tools: env-setup.sh so the validation toolchain is reproducible, not ad hoc
    requirements.txt only ever covered the analysis layer. Everything under validation/
    needs external solvers (GetDP, CalculiX, ngspice, gmsh, scikit-fem) and a LaTeX
    install, and those were rebuilt by hand each time the working environment was reset.
    env-setup.sh installs the lot and verifies every binary and import before exiting
    non-zero. It also encodes the two failures that cost time: apt-get update must run
    first against a stale container index, and texlive-latex-extra is excluded on purpose.
    Also corrects README's cross-check count from two to three -- A1's magnetostatic FEM
    is a third independent check and SUM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
2026-07-30 Add the silo launch study and a labelled coursework section
    The silo paper selects a coilgun where EMOCD rejects one: the same trade
    resolved oppositely because both are sized by s_min = v^2/2ng against what the
    payload tolerates -- 8.5 g on a propellant grain, 10.7 g on a CubeSat.
    It also carries the properly-referenced coilgun efficiency survey (5-25 percent
    by scale) that ADR-003 asserted without a source and got wrong.
    docs/SKILLS.md states the provenance rule the rest of the repository already
    follows, applied to this page: a claim has to be checkable against the artifact
    it names. Peer-reviewed names its venue, coursework names its course, and
    unsubmitted is called a manuscript.
2026-07-30 silo paper revalidated: 53 of 55 claims reproduce, two do not
    Recomputed every number in the silo launch paper from scratch, the original
    calculations having been lost. Only the paper's own stated inputs and formulas
    were used.
    Ballistics, Table I energy, all 22 Table II g-load values, both s_min figures, and the
    capacitor and supercapacitor sizing all reproduce.
    Table III's rate of fire does not, in both optimistic-efficiency rows. The caption
    declares t_index = 1.5 s; the two conservative rows are consistent with that, the two
    optimistic rows imply 1.98 s and 0.74 s. Correct range is 10.6-15.0 rounds/min, not the
    10.6-18.5 the conclusion prints -- the top of the range is 19 percent overs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
2026-07-30 Normalise typography and tighten wording across the documentation
    Replace em dashes, unicode arrows and multiplication signs with plain punctuation
    throughout, and rework the sentences that leaned on them. Code spans, fenced blocks
    and quoted source text keep their original characters.
    Also switches a few passages from third person to first, refreshes BASELINE.md after
    the generator changed, and rebuilds the CV.
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2026-07-30 Rebuild the companion front pages and repoint the exporter
    The exporter's manifests still referenced the ten documents at the repository root, so
    regenerating would have failed on every one of them. Repointed at docs/, and the prior
    art, literature landscape and related work now ship with both companions.
    Both README templates rewritten as landing pages rather than notices: the paper package
    leads with one reproduce command and a table of what cross-checks against what, the
    thesis package with a reading order for an examiner. The lab seed gains the two Phase II
    items that came out of reading the nearest published work.
2026-07-30 Animate the shot, and fix the stale stroke time it exposed
    paper/make_animation.py draws position, velocity, commanded force and bank current
    across the stroke, calling motor_model.shot(trace=True) so the animation and the paper's
    numbers come from one integrator.
    Building it surfaced P24. The stroke time printed in six places was 127.7 ms; the script
    gives 157.3 ms. Under constant acceleration the stroke time is 2s/v, so 127.7 ms belongs
    to the superseded 20.37 m/s point and survived the P8/P15 propagation.
    The prose is corrected. A8's declared band is not. It was set at 127.7 ms +/-10 %, and
    the current value sits 23 % above the band centre and outside it, so the recorded pass is
    a pass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
2026-07-30 Refresh the issue seeder and add repository topics
    The seeder still listed A1 as pending work; it has run. Replaced with the current
    roadmap, and four defects that did not exist when it was written: P22 prior art, P23 the
    stale stroke time, E24 the indexing disturbance, and PII-6 adopting reachable-domain
    analysis. Two labels added so the board can separate a stale operating point from a real
    defect.
    Repository descriptions rewritten and topics added, including on the three companions,
    which had none and were invisible to the search most people use.
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2026-07-30 Model the bank ESR, rename repository URLs to VOLLEY, refresh stale claims
    A8-R failed its energy-closure band at 97.0 %. The gap was the supercapacitor
    bank's own series resistance, which the circuit deck carried and no analysis
    script did.
    motor_model.py gains R_ESR and solves for the current the load draws at the bank
    terminal rather than at the capacitor, integrating Vc*I out of the bank and I^2 R
    into a new Q_esr output. sizing.py follows, energy_closure() carries the term on
    both sides, and thermal_campaign()'s literal 160 J placeholder becomes the
    computed 85.6 J.
    Eleven result fields moved, all electrical or thermal: energy drawn 2795.6 to
    2881.2 J, peak current 330.3 to 346.8 A, s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
    [motor_results.json]
2026-07-30 Refresh the issue seeder against the current defect list
    The A8 re-run it filed is done. Replaced with the two items that came out of it:
    sourcing the 12 mohm bank ESR, which is what keeps E17 open now that the
    modelling gap is closed, and P24 itself. The stroke-time entry it filed as P23 is
    closed by A8-R.
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2026-07-31 Regenerative braking: 297 J of the sled's 1291 J comes back
    A11 ran and held eight of eight declared bands. Braking at the rated sheet
    current over the 240 mm the closed envelope allows past release returns 296.6 J
    to the bank, 23.0 % of the sled's energy, and lifts electrical-to-payload
    efficiency from 19.0 to 21.2 %. Exit velocity is untouched at 16.537 m/s and
    asserted, since regeneration acts after release.
    The eddy brake stays and still absorbs 952 J. The 2025 decision was right that
    the motor cannot arrest the sled; it never argued that no energy could be
    recovered, and five documents had been carrying the wider claim. Each is
    corrected in place with the old text visible.
    regen_brake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
    [motor_results.json]
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2026-08-03 The winding-thickness quadrature was high, and the rated point moves to 16.388 m/s
    The winding-thickness average in both motor_model.py and A1 used endpoint-inclusive samples with an unweighted thickness/sample-count sum. They therefore agreed with each other while sharing the same quadrature defect.
    I replaced that average with nine-point Gauss-Legendre quadrature before rerunning either side. The rated model now gives Kt = 11.0258 N per kA/m (11.03 displayed), +/-0.99% ripple, 1389.255 N thrust, 16.388 m/s at 10.533 g in 158.6 ms, and 338.8 A peak current. The bank supplies 2850.9 J; 291.4 J returns during regenerative braking; the eddy brake absorbs 934.7 J; and net electrical-to-payload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
    [motor_results.json]
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

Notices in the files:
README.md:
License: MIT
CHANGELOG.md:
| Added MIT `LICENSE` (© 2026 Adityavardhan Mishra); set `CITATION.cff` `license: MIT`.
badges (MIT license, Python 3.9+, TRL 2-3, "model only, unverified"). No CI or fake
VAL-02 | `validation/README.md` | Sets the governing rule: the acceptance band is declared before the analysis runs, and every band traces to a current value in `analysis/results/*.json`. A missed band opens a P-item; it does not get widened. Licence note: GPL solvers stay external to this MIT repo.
